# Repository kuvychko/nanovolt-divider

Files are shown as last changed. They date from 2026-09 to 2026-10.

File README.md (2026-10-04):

# nanovolt-divider

A programmable precision attenuator for nanovolt-to-microvolt experiments: it divides an ordinary
bench power supply down by **passive resistive division**, read by an external precision DMM. Three
ratios (1e-5, 1e-6, 1e-7), relay-controlled polarity reversal for ABBA modulation, and a
source-disconnected baseline that opens the source without touching the measurement path.
Calibration is in progress (see [Status](#status)).

| | |
|---|---|
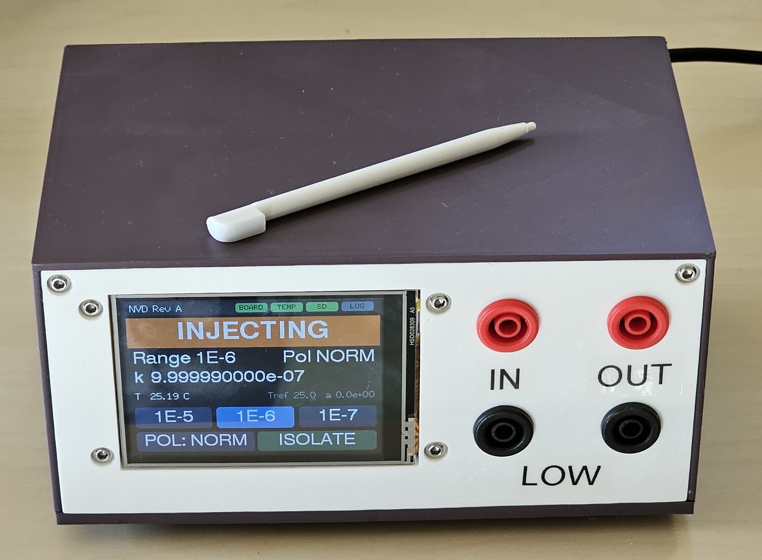
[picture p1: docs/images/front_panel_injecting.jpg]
Front panel, INJECTING on the 1E-6 range
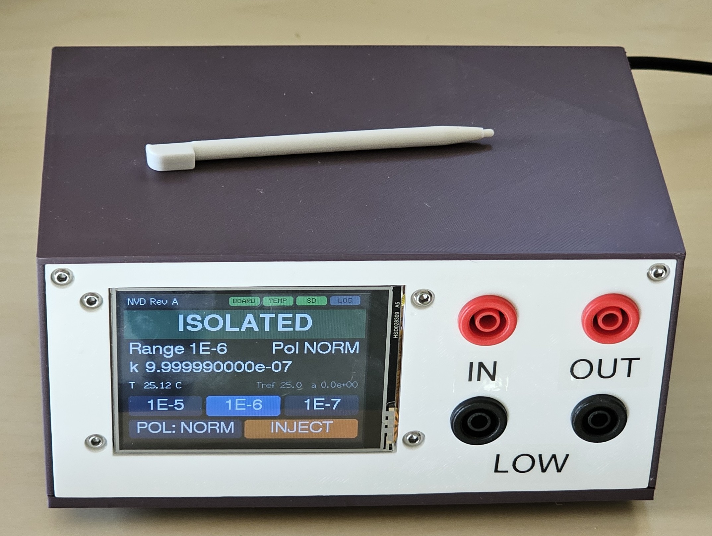
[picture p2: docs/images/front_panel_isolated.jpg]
Front panel, ISOLATED
|  |  |
| INJECTING: K5 set, the source drives the 1E-6 divider | ISOLATED: the source is open at both ends, the 1 Ω and OUT jacks stay connected |

| | |
|---|---|
| Ranges | `1E-5`, `1E-6`, `1E-7`: high legs of 100 kΩ (0.1 %, 5 ppm/°C), 1 MΩ (0.1 %, 10 ppm/°C) and 10 MΩ (1 %) over one shared 1 Ω low leg |
| Polarity | K4 reverses the source *upstream* of the high leg, so relay-contact EMFs reach the output divided by ~1/k |
| Baseline | ISOLATE opens the source at both ends; the 1 Ω, its Kelvin taps and the DMM path are never switched |
| Switching | Five latching relays, pulsed for 20 ms and never held: no continuous coil power |
| Temperature | TMP275 on a slotted island next to the 1 Ω |
| Calibration | Per-range k(T) = k0 [1 + α(T−T0) + β(T−T0)²] with uncertainties, stored in NVS and backed up to microSD |
| Control | SCPI over USB serial, and a 2.8" touchscreen (ESP32 "Cheap Yellow Display") |

## Status

Rev A is built and verified: all relay transitions work, and with 10 V applied all three ratios read
within 0.25 % of nominal, with the ISOLATE reading unchanged by the source. Firmware is 0.2.0.

**Calibration is in progress.** Until it completes, the instrument carries nominal ratios with
tolerance-sized uncertainties. The method, and each result as it comes in, are in
[docs/calibration.md](docs/calibration.md).

## Documentation

| Document | Contents |
|---|---|
| [docs/nanovolt_divider_rev_a.md](docs/nanovolt_divider_rev_a.md) | Design: architecture, relay rules, control, calibration model, BOM |
| [docs/hardware.md](docs/hardware.md) | Circuit, relay states, display harness wiring, board layout and routing rules |
| [docs/development.md](docs/development.md) | Opening the KiCad project, the ERC/DRC baseline, the generators and router, fabrication files |
| [docs/host_interface.md](docs/host_interface.md) | Driving it from a computer: the USB link, the reset-on-open trap, the SCPI contract |
| [docs/calibration.md](docs/calibration.md) | How the ratios are calibrated, the uncertainty budget, and the results so far |
| [firmware/README.md](firmware/README.md) | Building and flashing, the full SCPI command reference, first power-on |

## Repository layout

```
docs/                      design, hardware, development, host interface, calibration
calibration/               calibration result data (summaries and figures)
enclosure/                 SOLIDWORKS parts (.SLDPRT), STEP, and 3D-print files (.3MF, .3DXML)
firmware/                  ESP32 firmware, PlatformIO: relay state machine, SCPI over USB, touch UI,
                           microSD calibration backup and run log
hardware/                  KiCad 10 project
  nanovolt-divider.kicad_pro
  nanovolt-divider.kicad_sch   root sheet: metrology topology (input, relays, high legs, 1 ohm, output)
  control.kicad_sch            ESP32 display-module harness, MCP23017, TMP275, power
  relay_channel.kicad_sch      generic latching-relay channel, instantiated 5x (K1..K5)
  nanovolt-divider.kicad_pcb   board: 60 x 69.1 mm, 2 layers
  nanovolt-divider.kicad_dru   custom DRC rules (1 ohm bridge track width)
  lib/                         project symbol and footprint libraries
  fab/                         Rev A Gerbers and drill files
tools/gen_schematics.py    generates the schematics and the project libraries
tools/gen_pcb.py           generates the placed, unrouted board
tools/route_pcb.py         grid maze router around the hand routes (see docs/hardware.md)
tools/route_hand.py        the hand routes and routing policy: the design intent of the routing
tools/pcb_io.py            pcbnew side of the router: dump pads, apply routes
tools/scpi.py              SCPI terminal for the instrument over USB serial (uv run tools/scpi.py)
```

## Building one

1. **Boards.** Zip the contents of `hardware/fab/` and order (they went to OSH Park). Everything is
   hand-solderable; the BOM is in [§11 of the design doc](docs/nanovolt_divider_rev_a.md#11-bom).
2. **Harness.** Wire the display module to `J7` / `J8` **by signal name, never by pad number**: the
   board silk does not match the module. The table is in
   [docs/hardware.md, Display harness](docs/hardware.md#display-harness).
3. **Enclosure.** Print and assemble it as below.
4. **Firmware.** Build, flash and power on following [firmware/README.md](firmware/README.md).

## Enclosure

The enclosure is 3D-printed. `enclosure/` has the SOLIDWORKS source (`.SLDPRT`), a neutral `.STEP`
and a print-ready `.3MF` for each part: front panel (it also serves as the display bezel), back
panel, base plate (v1), cover (v1), PCB holder, and a wrench for the banana-jack nuts. The version
is in each file name.

Every part prints in PLA on a Prusa i3 MK3S with a 0.4 mm nozzle, using PrusaSlicer's
**0.20 mm QUALITY** preset, 15 % infill, and **no supports**.

Before assembling, heat-set the knurled brass inserts: the M2 ones go into the PCB holder, the M3
ones into the enclosure parts. Fasteners, banana jacks, the display module, and the cables are
listed in [BOM §11.4 and §11.5](docs/nanovolt_divider_rev_a.md#114-front-panel--mechanical).

| | |
|---|---|
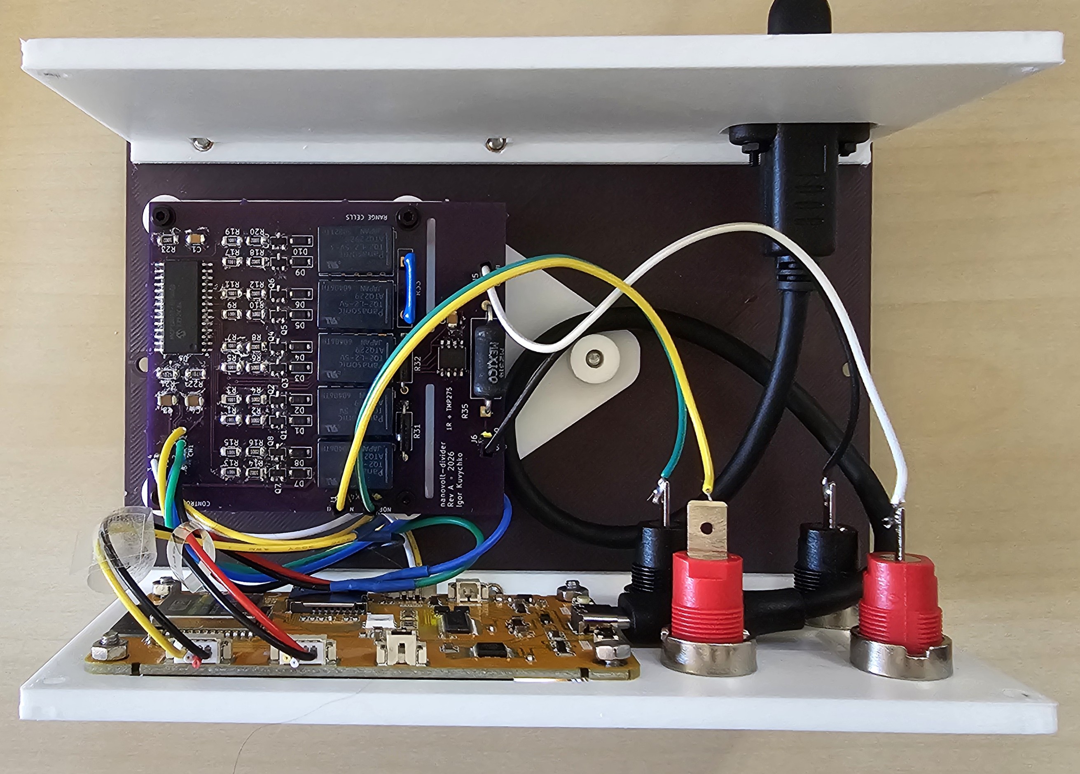
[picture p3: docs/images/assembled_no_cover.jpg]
Assembled, cover off
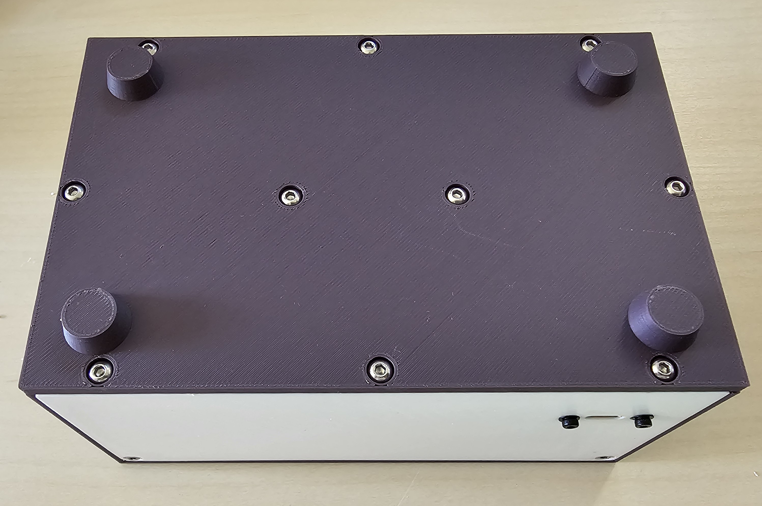
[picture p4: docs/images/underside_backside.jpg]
Base plate and back panel
|  |  |
| Cover off: the board on its holder, the display behind the front panel, and the jacks wired to their pads | Base plate with printed feet, and the back panel with the USB opening |

## Known limitations

* The board's harness silk and F.Fab text describe a different module pinout from the module the
  instrument uses. Wire by signal name (see
  [Display harness](docs/hardware.md#display-harness)).
* The harness cable has no strain relief at the board end; nothing on the board takes that load.

## Datasheets

Not redistributed here. Panasonic TQ relays: catalog ASCTB14E (`industry.panasonic.com`); Ohmite
MOX-700 and Slim-Mox; Vishay Dale RS/NS; Microchip MCP23017; TI TMP275.

## License

* Hardware (`hardware/`), enclosure (`enclosure/`) and documentation (`docs/`, `calibration/`):
  [CERN-OHL-P-2.0](LICENSE-CERN-OHL-P-2.0).
* Firmware (`firmware/`) and tools (`tools/`): [MIT](LICENSE-MIT).

Source location: <https://github.com/kuvychko/nanovolt-divider>. See [LICENSE](LICENSE).

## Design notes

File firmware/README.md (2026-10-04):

# Rev A firmware

Firmware for the ESP32 "Cheap Yellow Display" (ESP32-2432S028R family) that runs the nanovolt divider:

* the relay state machine for K1..K5, through the MCP23017;
* the TMP275;
* per-range calibration k(T) in NVS, with a backup, an append-only history and a CSV run log on the microSD card;
* SCPI over USB serial;
* the touchscreen front panel.

The instrument is controlled over USB from a host computer (e.g. a Raspberry Pi): see
[docs/host_interface.md](../docs/host_interface.md) for the host side, and
[docs/calibration.md](../docs/calibration.md) for how the calibration is measured. **The radio is never
initialised:** there is no Wi-Fi or Bluetooth, and no 2.4 GHz transmitter a few centimetres from a nanovolt path.
The module's RGB LED is held off; it is inside the enclosure.

## Build and flash

The project uses PlatformIO. Install it with `uv tool install platformio`. Set `upload_port` and `monitor_port`
in `platformio.ini` to your module's serial port (they are `COM8` there), and pass `-p <port>` to `tools/scpi.py`.

```
pio run -d firmware -e cyd -e cyd_st7789 -e cyd_sim   # build every environment (plain `pio run` builds only cyd)
pio run -d firmware -e cyd -t upload       # flash
uv run tools/scpi.py -p <port>             # interactive SCPI terminal
uv run tools/scpi.py -p <port> "*IDN?" "SYST:MODE?"  # one-shot
```

| Environment | Use |
|---|---|
| `cyd` | Standard CYD with an ILI9341 panel. The default. |
| `cyd_st7789` | CYD2USB variant (two USB ports) with an ST7789 panel. Use it if `cyd` shows garbage or wrong colours. `DIAG:DISP:INV ON` flips the colour inversion at run time, to help tell the variants apart. |
| `cyd_sim` | No board needed. The MCP23017 and TMP275 are simulated, and every coil pulse is printed as `# PULSE K5 RESET (GPA0) 20 ms`. Use it to check relay sequencing. |

The platform is pinned to `espressif32@7.1.3` (Arduino core 2.0.17) and `LovyanGFX@1.2.30`. Core logging is compiled
out (`CORE_DEBUG_LEVEL=0`), because it would land in the SCPI response stream. The firmware's own unsolicited lines
(the boot banner and the pulse trace) all start with `# `, so a host can skip them.

## How it drives the board

* **I2C is SDA = IO27, SCL = IO18.** See [docs/hardware.md, "Display harness"](../docs/hardware.md#display-harness).
* **Coil table.** The table is in `src/coils.cpp`, and nowhere else. It follows the layout order: GPB0..7 = K4 S, K4 R,
  K1 S, K1 R, K2 S, K2 R, K3 S, K3 R; GPA0 = K5 R, GPA1 = K5 S. GPA2..7 stay inputs.
* **One coil at a time.** Every pulse first confirms that both output latches read back 0. It then sets one bit,
  holds it for the pulse width (20 ms by default), clears it, reads the latches back again, and waits the gap
  (20 ms).
* **The MCP23017 survives an ESP32 reboot.** R23 ties `~RESET` high, so a reboot mid-pulse would leave a coil
  energised. Boot therefore clears OLATA/OLATB before anything else, including before it makes any pin an output.
* **Relay rules ([design §6.3](../docs/nanovolt_divider_rev_a.md#63-relay-safetystate-rules)).**
  * At boot, and on `*RST`, the firmware pulses the safe state: K5 RESET (ISOLATE) first, then K1..K3 RESET, then K4
    RESET.
  * A range or polarity change runs this sequence:
    1. isolate;
    2. RESET the old range (break);
    3. SET the new one (make);
    4. restore INJECT if it was on.

    For example, `RANG 1E-6` while injecting on 1E-5 pulses K5R, K1R, K2S, K5S.
  * INJECT is refused while no range is selected.
* **State is assumed, not measured.** Latching relays cannot be read back. The state shown is what the last successful
  pulses produced. It is `UNKNOWN` until the boot safe state has run, and after any failed pulse or raw `DIAG:PULS`.
  While the state is unknown, all relay commands except `*RST` are refused. On the touchscreen, tap the red banner.
* **No board.** With no MCP23017 answering, the screen shows `NO BOARD` and relay commands return `-241`. The firmware
  re-probes every 2 s. A board that appears later is never pulsed automatically: its state is `UNKNOWN` until
  `*RST`.

### microSD and the shared IO18

The card's SCK is IO18, which is also I2C SCL. The bus stays in I2C mode, and each card access switches it to SPI,
mounts the card, does the work, unmounts and switches back (`bus::SdSession`). This is safe both ways:

* I2C traffic clocks SCK while the card's CS is held high, so the card ignores it.
* SPI clocking toggles SCL while SDA idles high, which never forms an I2C START.

Card access happens only between operations, never during a coil pulse. The touch controller is bit-banged on its own
pins, because the only free SPI host belongs to the card.

Files on the card:

| Path | Contents |
|---|---|
| `/nvd/cal.txt` | Calibration backup (`CAL:EXP` / `CAL:IMP`): one `key=value` line per range, `range= k0= t0= alpha= beta= u_k0_ppm= u_alpha_ppm= tmin= tmax= date="" source=""`. An import requires every field. |
| `/nvd/cal_history.txt` | Every `CAL:SAVE`, appended: a `# CAL:SAVE utc=… boot=…` line and the three records. The firmware never rewrites or deletes it. |
| `/nvd/log_NNNN.csv` | Run log: `ms,utc,event,range,polarity,output,temp_C,factor,note`. It gets a row for every relay change, for every `SYST:LOG:MARK`, and a `TEMP` row every `SYST:LOG:INT` seconds (default 10; 0 turns it off). `utc` is `-` until the host sends `SYST:TIME`. |

`MMEM:CAT?` and `MMEM:DATA?` read these over USB, so the card never has to come out:
`uv run tools/scpi.py --fetch /nvd/cal_history.txt hist.txt`. From Git Bash, prefix the command with
`MSYS_NO_PATHCONV=1`, or Bash rewrites `/nvd/...` into a Windows path.

### Calibration model

```
k(T) = k0 · [1 + alpha (T − T0) + beta (T − T0)²]
u(T) = sqrt(u_k0² + (u_alpha · (T − T0))²)   ppm
```

T is the TMP275 reading. Each range carries its own record, including the span [tmin, tmax] it was measured over.
Before calibration the records are nominal: k0 = 1/(R_H + 1), no tempco, and u_k0 from the part tolerances
(10050 / 10050 / 14142 ppm). Records are stored as one NVS blob per range, so a save is all-or-nothing per range.

## SCPI reference

These rules apply to every command:

* Headers match in long or short form, case-insensitively.
* A leading `:` is optional.
* `;` separates commands on one line. The responses to all the queries on a line come back joined by `;`.
* Errors go to the queue, which `SYST:ERR?` reads. A value that does not exist, such as the factor with no range
  selected or a missing temperature, reads `9.91E+37`.

| Command | |
|---|---|
| `*IDN?` `*RST` `*CLS` `*OPC?` | `*RST` pulses the safe state. |
| `SYST:ERR?` `SYST:VERS?` | |
| `SYST:MODE?` | Full state: `BOARD=,STATE=,RANGE=,POL=,OUTP=,TEMP=,FACTOR=,CAL=,LOG=,BOOT=`. |
| `SYST:TIME <unix s>` / `SYST:TIME?` | UTC from the host, kept in RAM (0 until set). Stamps the run log and the cal history. |
| `SYST:BOOT:COUNT?` `SYST:UPT?` | Boots since the NVS was first written, and seconds since this boot. The count changing mid-run means the instrument restarted. |
| `OUTP ON\|OFF` / `OUTP?` | INJECT / ISOLATE. `OUTP OFF` always pulses, even if already isolated. |
| `POL NORM\|INV` / `POL?` | Changes happen while isolated. |
| `RANG 1E-5\|1E-6\|1E-7\|NONE` / `RANG?` | Break-before-make, while isolated. |
| `SOUR:FACT? [T]` | Calibrated factor of the active range, at the live TMP275 temperature or at T. |
| `CAL:FACT? range[,T]` | `k,u_ppm,in_span` for any range, at the live temperature or at T. `in_span` is 0 outside the record's [tmin, tmax] or with no temperature. |
| `CAL:REC range,k0,T0,alpha,beta,u_k0_ppm,u_alpha_ppm,tmin,tmax,"date","source"` / `CAL:REC? range` | One range's whole record, written atomically: any invalid field rejects the lot. The query returns the same fields after the range. This is the command the calibration write-back uses. |
| `TEMP?` | TMP275, °C. |
| `CAL:RAT [range,]k` / `CAL:RAT? [range]` | k0. The range defaults to the active one. Values more than 10 % from nominal are rejected. |
| `CAL:TC [range,]alpha` / `CAL:TC?` | Ratio tempco, 1/°C. The default 0 means no correction. |
| `CAL:TREF [range,]T0` / `CAL:TREF?` | Reference temperature, °C. |
| `CAL:DATE [range,]"text"` / `CAL:DATE?` | Free text, e.g. an ISO 8601 date. |
| `CAL:NOM? [range]` | Nominal factor, 1/(R_H + 1). |
| `CAL:SAVE` | Writes the working calibration to NVS and appends it to `/nvd/cal_history.txt`. The other `CAL:` edits change only the working copy (`SYST:MODE?` shows `CAL=UNSAVED`). If the history append fails, the save still stands and `-250` is queued. |
| `CAL:DEF` | Resets the working copy to nominal. |
| `CAL:EXP` / `CAL:IMP` | Writes the working copy to `/nvd/cal.txt`, or reads it back from there. `CAL:SAVE` after an import. |
| `SYST:LOG ON\|OFF` / `SYST:LOG?` | Starts a new `/nvd/log_NNNN.csv`, or stops logging. |
| `SYST:LOG:FILE?` `SYST:LOG:MARK "text"` `SYST:LOG:INT s` | Log file name, a note row (e.g. `"A forward"` during an ABBA run), and the temperature-row interval. |
| `SYST:BOOT:SAFE ON\|OFF` | Whether boot pulses the safe state. Stored in NVS; the default is ON. |
| `MMEM:CAT? ["dir"]` | `"name",size,...` for a directory, `/nvd` by default. |
| `MMEM:DATA? "path"[,offset[,length]]` | Up to 65536 bytes of a file, as an IEEE 488.2 definite-length block `#<n><len><bytes>` followed by `\n`. Must be the only command on its line. |
| `DIAG:I2C?` | Bus scan. Expect `0x20,0x48` with the board connected. |
| `DIAG:MCP?` | MCP23017 register dump. |
| `DIAG:PULS K1..K5,SET\|RES` | One raw pulse, bypassing the rules. Leaves the state `UNKNOWN`. |
| `DIAG:PULS:WIDT ms` / `DIAG:PULS:GAP ms` | 5..100 ms. Stored in NVS. |
| `DIAG:TRAC ON\|OFF` | Prints each pulse as `# PULSE ...`. |
| `DIAG:PINS?` | IO18/IO27 read with internal pull-downs: `PULLUP` means an external pull-up is fitted. |
| `DIAG:SD?` | Card type and size. |
| `DIAG:TOUC:CAL` / `DIAG:TOUC?` | Runs the 3-point touch calibration, or returns the current raw and mapped touch point. Holding the screen at power-up also starts the calibration. |
| `DIAG:DISP:INV ON\|OFF` | Panel colour inversion (not stored). |

## First power-on with the board

Before you start, flash the `cyd` build with the module alone, and set `SYST:BOOT:SAFE OFF`. That way the first coil
pulses are ones you fire by hand, not five at once at boot.

1. **Harness.** Land every wire by signal name ([docs/hardware.md, "Display harness"](../docs/hardware.md#display-harness)). The J7 silk numbers are
   reversed against the module. With the power off, buzz the harness from the module pins to the pads:

   | Module pin | Board pad |
   |---|---|
   | 5V | `J7` pad 3 |
   | GND (UART/power connector) | `J7` pad 4 |
   | GND (3V3 connector) | `J8` pad 1 |
   | IO18 | `J8` pad 2 |
   | IO27 | `J8` pad 3 |
   | 3.3V | `J8` pad 4 |

   A reversed 5 V would reach the coil drivers the moment USB is plugged in, so this check comes before any power.
2. **Power on.** The banner should read `STATE UNKNOWN`, and the `BOARD` and `TEMP` status lights should be green.
3. `DIAG:I2C?` should return `0x20,0x48`. `DIAG:PINS?` should now report `PULLUP` on both pins: those are R21/R22,
   because the module itself has none (with the module alone, `DIAG:PINS?` reads `IO18=NONE,IO27=NONE`).
4. `DIAG:MCP?` should show `IODIRA=0xFC`, `IODIRB=0x00` and both `OLAT` registers `0x00`.
5. `TEMP?` should give a plausible room temperature.
6. `DIAG:TRAC ON`, then pulse each coil by hand, listening for the click and ideally watching the collector on a scope:

   ```
   DIAG:PULS K5,RES
   DIAG:PULS K5,SET
   DIAG:PULS K5,RES
   ```

   Repeat for K1..K4. With a meter on the contacts, check each relay's pole against the state table in the top-level
   README.
7. `*RST` should pulse the whole safe state. Then `SYST:BOOT:SAFE ON`, and power-cycle to confirm the boot sequence.
8. Walk the ranges with `OUTP ON`, `RANG 1E-6`, `POL INV` and so on, meter the output, and check `SYST:ERR?` is clean.

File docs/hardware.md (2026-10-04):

# Hardware

The Rev A circuit, the display harness, the board layout and the routing rules. Building and flashing are in
[firmware/README.md](../firmware/README.md); regenerating and checking the design files is in
[development.md](development.md); the design rationale and BOM are in
[nanovolt_divider_rev_a.md](nanovolt_divider_rev_a.md).

## Circuit

### Hierarchy

```
nanovolt-divider.kicad_sch (root)
+-- CONTROL          control.kicad_sch
+-- RANGE_1E5 (K1)   relay_channel.kicad_sch
+-- RANGE_1E6 (K2)   relay_channel.kicad_sch
+-- RANGE_1E7 (K3)   relay_channel.kicad_sch
+-- POLARITY  (K4)   relay_channel.kicad_sch
+-- INJECT    (K5)   relay_channel.kicad_sch
```

`relay_channel.kicad_sch` exposes `SET`, `RESET`, `A_COM`, `A_NC`, `A_NO`, `B_COM`, `B_NC`, `B_NO`.
Each instance contains one Panasonic TQ2-L2-5V (2-coil latching DPDT) and two MMBT2222A low-side
coil drivers with 1N4148W flyback diodes.

### Relay states

| Relay | RESET (NC) | SET (NO) |
|---|---|---|
| K4 POLARITY | normal (`SRC_P` = `NORMAL_IN_P`) | inverted |
| K1..K3 RANGE | open at both ends | range active (only one at a time) |
| K5 INJECT | ISOLATE - both legs open (1 ohm and DMM path untouched) | INJECT |

K1..K3 use **both** poles of their relay: pole A breaks the top of the high leg (`R*_IN`), pole B
breaks the bottom (`R*_OUT`). A deselected resistor is therefore isolated at both ends and never
loads `RANGE_BUS`, which matters most on the 10 M range.

K5 does the same for the source as a whole: pole A breaks the high side (`RANGE_BUS` -> `MEAS_NODE`)
and pole B breaks the return (`SRC_RTN` -> `ANALOG_RTN`). In ISOLATE the source is disconnected
from the 1 ohm and the DMM path at both ends, so nothing of it - not its output capacitance, not its
leakage to earth - remains attached to the measurement node.

### Control wiring

* Controller: a 2.8" ESP32 touch-TFT module, a "Cheap Yellow Display" (ESP32-2432S028R family),
  mounted off-board and connected by three of its own pigtails (see [Display harness](#display-harness)).
* The pigtails are **soldered** to pads at the board end; the module end keeps its connector, so
  the display still unplugs. The panel jacks (`J1`, `J2`, `J5`, `J6`) are hard-wired the same way.
* Only the six live conductors have pads: `J7` (5 V, GND) and `J8` (GND, SCL, SDA, 3V3). Both GND
  wires are run: `J7`'s returns the pulsed coil current and `J8`'s serves I2C. They are the same
  net, but two conductors cut the shared IR drop in the cable. Do not collapse them to one wire.
* MCP23017 (I2C 0x20) drives the ten coil lines: GPB0..GPB7 = K4 SET, K4 RESET, K1 SET, K1 RESET,
  K2 SET, K2 RESET, K3 SET, K3 RESET; GPA0 = K5 RESET, GPA1 = K5 SET; GPA2..GPA7 spare. The order
  follows the board: in the driver columns' left-to-right order the lines fan out without a
  crossing or a via. The firmware maps GPIO to coil by table.
* TMP275 (I2C 0x48, `A2:A0` all on `DGND`) sits next to the 1 ohm resistor, thermal proximity only.
  It tracks the *change* in the 1 ohm region's temperature for the ratio correction, which needs
  short-term repeatability (12-bit, 0.0625 C) rather than absolute accuracy (+/-0.5 C). SOIC-8, so the
  whole board can be hand-soldered.
* The control ground is the global net `DGND`, deliberately not `GND`, so it cannot be merged with
  the floating analog return (`SRC_RTN` / `ANALOG_RTN`) by accident.

### Display harness

The module has three 4-pin connectors:

| Module connector | Signals, in the order printed on the module |
|---|---|
| UART / power | RXD, TXD, GND, 5V |
| 3V3 | 3.3V, IO35, *(nc)*, GND |
| SPI | IO23 (MOSI), IO19 (MISO), IO18 (SCK), IO27 (CS) |

Wire them to the board like this:

| Board pad | Net | Wire from module | Pad silk |
|---|---|---|---|
| `J7` pad 3 | `+5V` | UART / power: **5V** | `P1` `3` |
| `J7` pad 4 | `DGND` | UART / power: **GND** | `P1` `4` |
| `J8` pad 1 | `DGND` | 3V3: **GND** | `CN1` `1` |
| `J8` pad 2 | `SCL` | SPI: **IO18** | `CN1` `2` |
| `J8` pad 3 | `SDA` | SPI: **IO27** | `CN1` `3` |
| `J8` pad 4 | `+3V3` | 3V3: **3.3V** | `CN1` `4` |
| - | - | cut back and insulate: RXD, TXD, IO35, the nc pin, IO23, IO19 | - |

* **Land every wire by signal name, never by pad number.** The silk numbers on the board do not
  match this module: on `J7`, module pin 3 is GND but pad `3` is `+5V`, so matching numbers would
  feed the coil drivers a reversed 5 V supply. The `J8` pad row is fed by two different pigtails, so
  its "CN1 1-4" silk refers to no single connector. The F.Fab text on the board (`SCL_IO22`,
  `VIN_5V`) does not match either. The schematic symbols carry the correct module labels.
* **Why IO18 / IO27.** I2C needs two pins that can drive open-drain. IO35 cannot (ESP32 GPIO34-39
  are input-only), and RXD / TXD carry the USB-serial SCPI interface, which leaves the SPI
  connector. Firmware: `Wire.begin(/*SDA*/ 27, /*SCL*/ 18)`.
* **IO18 is shared with the microSD slot** (its SCK; the slot has its own CS on IO5). With the card's
  CS deasserted, I2C traffic on IO18 does not disturb it; the firmware switches IO18 between I2C and
  SPI around each card access (see [firmware/README.md](../firmware/README.md)). The module has no pull-ups on IO18 or IO27,
  so `R21` / `R22` set the bus pull-up.
* Both GND conductors run from different connectors: the UART / power GND to `J7` (coil current) and
  the 3V3 connector's GND to `J8` (I2C).

## Board

| | |
|---|---|
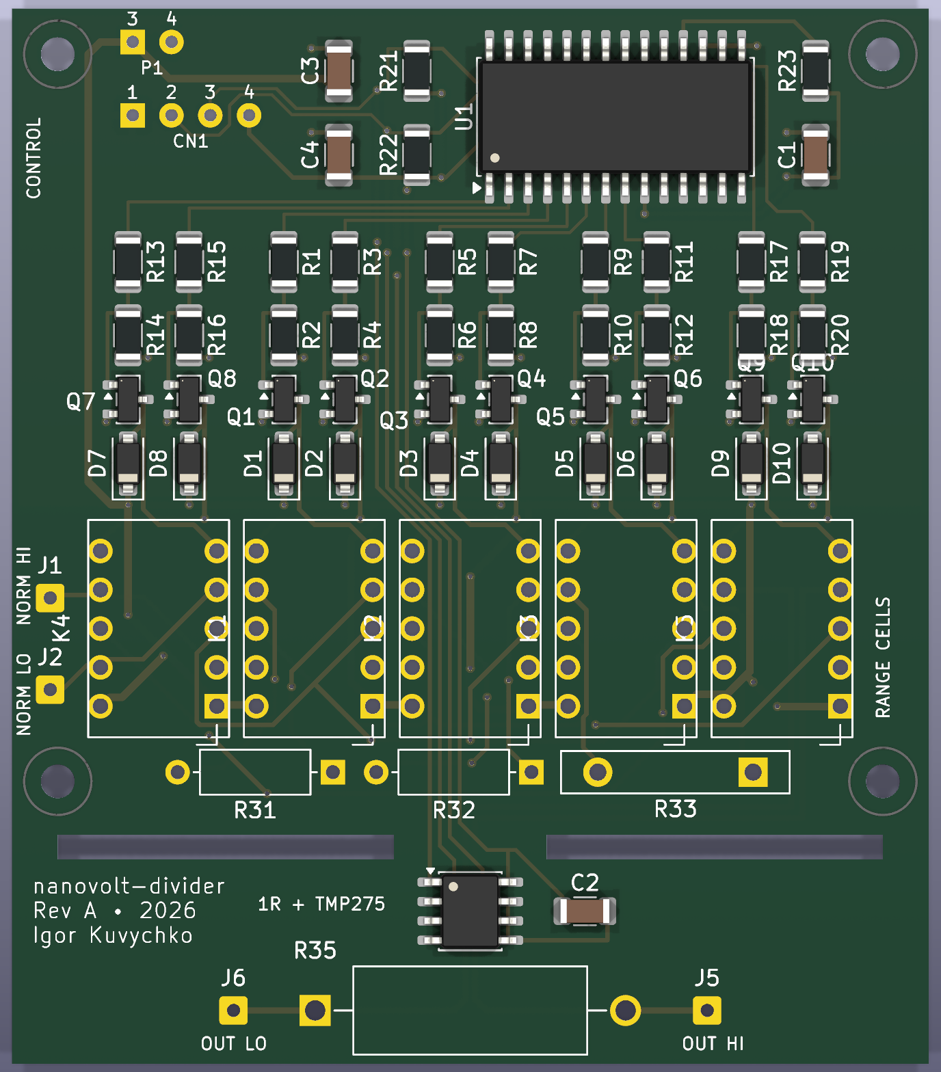
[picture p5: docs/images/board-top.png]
Rev A board, top (render)
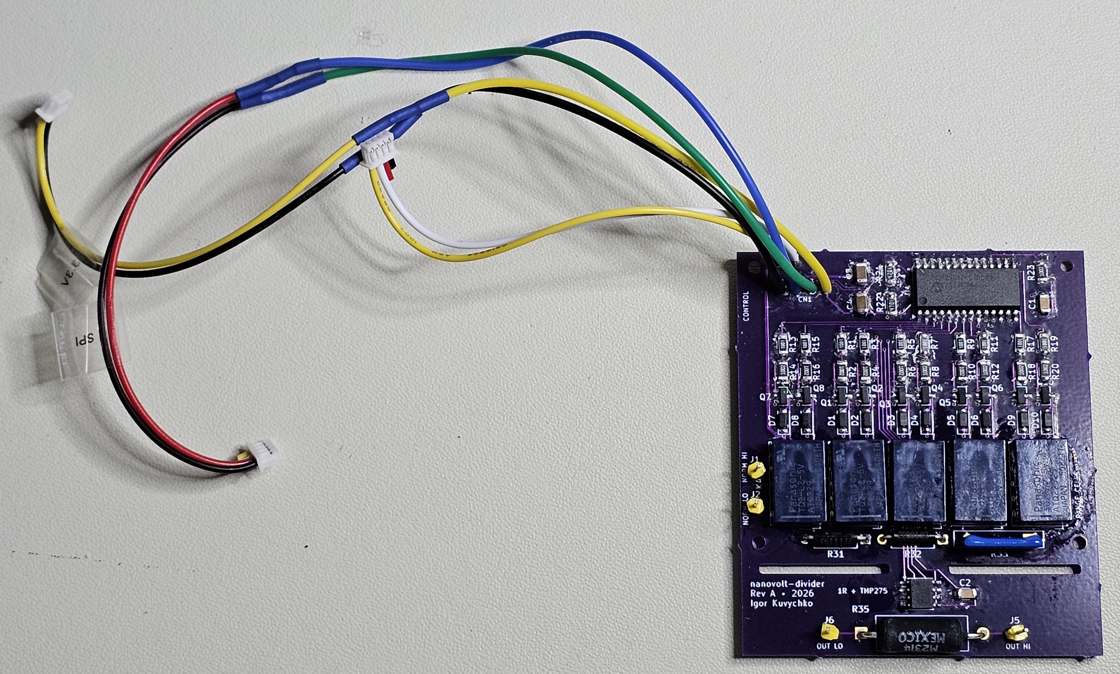
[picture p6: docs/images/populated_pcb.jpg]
Rev A board, populated, with the display harness
|  |  |
| Layout render | Populated Rev A with the harness pigtails soldered to `J7` / `J8` |

* 60 x 69.1 mm, two layers, laid out top-down: one control band, ten coil-driver columns, the five
  relays, then the three high legs flat in one row.
* **The control band is a single row**: `[H1] P1/CN1 | C3,C4 | R21,R22 | U1 | R23,C1 [H2]`. The bulk
  caps sit at the power entry, the I2C pull-ups between the harness and `U1` so the bus runs left to
  right, and `C1` beside `U1`'s power pins.
* **Driver cells.** Each relay carries its SET/RESET driver pair directly above it, so `RANGE_BUS`
  runs as one short chain across the three range cells.
* **The three high legs lie flat in one row** under the relays. `A_NO` and `B_NO` are both on each
  relay's upper contact row, and the flat, offset placement keeps both runs to 2-5 mm.
* **M2 mounting holes.** The smaller courtyard lets the holes sit closer to `K4`/`K5` above and the
  slots below, which saves board height.
* The relay coils are pulsed for 20 ms and never held, so their average dissipation is ~0 and they
  can sit next to the range resistors. The continuously powered parts (MCP23017, harness pads, bulk
  caps) stay at the top edge, away from `MEAS_NODE`.
* **The 1 ohm island.** Two slots leave a 10 mm centre bridge and 3 mm bridges at both board edges
  for stiffness; `MEAS_NODE`, `ANALOG_RTN` and the TMP275 lines cross the centre one. The OUT HI / OUT
  LO wire pads are at the resistor's own terminals. Both lower mounting holes sit *above* the slots:
  a screw on the island would add a thermal and mechanical-stress path to the precision resistor.
* The TMP275 sits on the island above `R35`. What couples the sensor to `R35` is the island copper,
  not the air over the body.
* **`J1` / `J2` sit beside `K4`**, opposite the K4 pole-B contacts they wire to, clear of the lower
  left mounting hole.
* `DGND` pour on B.Cu covers the digital circuitry (control cluster and coil drivers). The only
  copper keepout is over the 1 ohm island.
* Panel parts (four banana jacks) terminate on solder-wire pads. Nothing is wired panel-to-panel,
  so every conductor appears in the netlist.

### Routing

The precision path, the driver cells and the whole control band are hand-laid
(`tools/route_hand.py`); a grid maze router (`tools/route_pcb.py`) filled in the rest around them.
Rules the routing follows, and that hand edits should keep:

* **`MEAS_NODE` and `ANALOG_RTN` run as one tight pair on B.Cu** from K5 to R35: 0.4 mm, 0.3 mm
  apart, via-free. `ANALOG_RTN` is on the side facing the high-leg pads, so it rather than
  `MEAS_NODE` takes any surface leakage from `R*_IN`. The pair crosses the centre bridge on the
  board's centre line and only splits under R35, along its axis, so the current loop is the
  resistor itself and both terminals have the same copper path back to the board.
* **Kelvin at R35.** The injection current lands on R35's pads from the inside; J5 / J6 (the DMM)
  leave them on the outside on F.Cu, and carry no current.
* **Source-side and low-side copper keep 0.5 mm apart on the same layer.** `SRC_P`, `NORMAL_IN_*`
  and `R*_IN` sit at the source voltage; `RANGE_BUS`, `R*_OUT` and `MEAS_NODE` at the bottom of the
  selected high leg. Leakage between them is a resistor across the high leg - 10 ppm at 1e12 ohm on
  the 10 M range. Where the two chains must cross they do it on opposite layers, through 1.6 mm of
  FR4 bulk. `SRC_RTN` / `ANALOG_RTN` are in neither class: leakage into them only loads the source.
* **Nothing reaches the 1 ohm island except over the centre bridge**, and the bridge carries no
  vias. A track over an edge bridge would bring heat in at one end of R35, and a temperature
  difference between its terminals is a thermal EMF in series with the measurement.
* **The TMP275 lines are one F.Cu spine**: SDA, SCL, DGND, +3V3 at 0.65 mm pitch, down the gap
  between the K1 and K2 driver pairs, through the left half of K2, under R32's body and onto the
  island left of the pair. The precision chains cross it on B.Cu.
* **Driver cells are identical.** Each column is the same template: the base node runs straight
  from the 1k to the 10k, which is why R1-R20 sit at 270 degrees. DGND goes to the B.Cu pour through
  a via beside the 10k and one beside the emitter; cathodes drop to a +5V bus on B.Cu at y 32.5 along
  the bottom of the pour.
* **One coil crossing per relay, the same for all five.** The SET column feeds the right-hand coil
  pin and the RESET column the left: SET stays on F.Cu, RESET drops to B.Cu. That leaves the left
  half of each relay's top free on F.Cu, which is how the TMP275 spine gets into K2.
* **The MCP23017 fan-out has no crossings and no vias.** Eight lines drop off U1's lower row in the
  driver columns' order, five of them left in 0.2 mm lanes at 0.4 mm pitch, and K5's two leave under
  the package to the right. SDA, SCL and 3V3 reach U1 under its body, stacked in the order they drop
  to pins 13, 12 and 9.
* **The control band's vias are each unavoidable:** the TMP275 spine's SDA, SCL and 3V3 each rise on
  B.Cu past the coil lanes; R21's 3V3 pad is fenced in by SDA and SCL; and C1/R23 sit beyond the K5
  lines, so their 3V3 hops from pin 9 on B.Cu. SDA and SCL squeeze between C3 and C4 in two 0.2 mm
  lanes; +5V comes down the left edge from P1.

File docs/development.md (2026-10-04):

# Development

Working on the KiCad design: opening it, the ERC/DRC baseline, the generators and router, and the
fabrication files. Commands run from the repository root. The circuit and board themselves are described in
[hardware.md](hardware.md).

## Working with the design files

Open `hardware/nanovolt-divider.kicad_pro` in KiCad 10. The project library
`hardware/lib/nanovolt-divider.kicad_sym` holds the TQ2-L2-5V relay, the TMP275, the `DGND` power
symbol and the two ESP32 harness pigtail landings. These carry the module's own pin names
(`SCL_IO18`, `SDA_IO27`, ...) rather than `Pin_1..Pin_4`, so a wire on the wrong pin is visible in
the schematic. The harness footprints are kept exactly as fabricated (`HARNESS_PADS_REV_A` in
`gen_schematics.py`), which is why their F.Fab names differ; see
[Display harness](hardware.md#display-harness). Footprints for the
relay, the precision resistors and the harness pads are in `hardware/lib/nanovolt-divider.pretty`;
the TMP275 uses the stock `Package_SO:SOIC-8_3.9x4.9mm_P1.27mm`. Everything else is stock KiCad.

ERC, DRC and exports from the command line:

```
kicad-cli sch erc --severity-all --exit-code-violations hardware/nanovolt-divider.kicad_sch
kicad-cli sch export pdf --output build/schematic.pdf hardware/nanovolt-divider.kicad_sch
kicad-cli pcb drc --severity-error --severity-warning hardware/nanovolt-divider.kicad_pcb
```

The baseline is ERC clean, and DRC 0 errors, 0 unconnected and 56 `silk_over_copper` warnings
(silkscreen clipped by solder mask at pad openings, which the fab does anyway). With
`--schematic-parity` there are also 2 `footprint_symbol_field_mismatch` warnings: the Description
field of `J7` and `J8` names the display module, while the board keeps the fabricated text. They
are metadata only. Check that a change does not add to this baseline.

### Generators

`tools/gen_schematics.py` generates all schematic files, the project symbol library and the project
footprints; re-run it after editing the script. It will **not** overwrite an existing
`nanovolt-divider.kicad_pro`, which KiCad owns and which holds the DRC severities. It writes its
files directly with derived UUIDs, so re-running it leaves the working tree clean.

`tools/gen_pcb.py` writes a placed, **unrouted** board from scratch, so running it discards the
routing and any hand edits. The router then reproduces the committed routing exactly (it deletes
every track before applying its own):

```
"C:/Program Files/KiCad/10.0/bin/python.exe" tools/pcb_io.py dump  hardware/nanovolt-divider.kicad_pcb %TEMP%/nvd_geom.json
uv run tools/route_pcb.py %TEMP%/nvd_geom.json %TEMP%/nvd_routes.json
"C:/Program Files/KiCad/10.0/bin/python.exe" tools/pcb_io.py apply hardware/nanovolt-divider.kicad_pcb %TEMP%/nvd_routes.json
```

**A regenerated board produces a large, meaningless diff.** `kicad-cli pcb upgrade` assigns fresh
random UUIDs to the graphics it materialises inside stock footprints, so about 683 of the board's
~1400 UUIDs change on every run, and `kicad-cli` writes CRLF while `.gitattributes` pins the repo to
LF. Neither is a real change. Before acting on a board diff, normalise both sides and compare:

```python
import re, io, subprocess
strip = lambda t: re.sub(r'"[0-9a-f]{8}-[0-9a-f]{4}-[0-9a-f]{4}-[0-9a-f]{4}-[0-9a-f]{12}"', '"U"',
                         t.replace("\r\n", "\n"))
cur  = io.open("hardware/nanovolt-divider.kicad_pcb", "rb").read().decode("utf-8")
head = subprocess.run(["git", "show", "HEAD:hardware/nanovolt-divider.kicad_pcb"],
                      capture_output=True).stdout.decode("utf-8")
print(strip(head) == strip(cur))    # True -> nothing changed; restore the file, do not commit it
```

Read both sides as bytes and decode UTF-8 explicitly. Decoding one side through
`subprocess.run(text=True)` uses the locale codec and manufactures fake differences around non-ASCII
characters - KiCad's stock `SolderWire` footprint description genuinely contains a U+FFFD.

What proves a board change is real is the exported netlist and an ERC/DRC comparison, not the
file diff.

## Fabrication files

`hardware/fab/` holds the Rev A Gerbers and drill files exactly as sent to the fab (OSH Park, git
tag `rev-a`). `.gitattributes` marks the folder `-text` so git leaves their CRLF line endings alone.
To order boards, zip the folder's contents. Two things to know about them:

* Their metadata says `Rev0` (`TF.ProjectId` in every Gerber, `Revision` in the job file). The
  copper is the Rev A board's: re-plotting the board and diffing against these files leaves only the
  creation date and the drill marks.
* They are plotted with drill marks **off**. The board file's stored plot settings have them on
  (small), so `kicad-cli pcb export gerbers --board-plot-params` adds a 0.3 / 0.35 mm flash at every
  hole on the copper and mask layers. Turn them off when re-plotting.

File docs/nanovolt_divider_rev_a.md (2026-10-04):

# Programmable Nanovolt Divider / Precision Attenuator
## Rev A design

**Revision:** Rev A, as built (fab files in `hardware/fab/`, enclosure in `enclosure/`)  
**Primary use:** calibrated low-level DC injection and sub-LSB metrology with an external precision DMM

---

## 1. Purpose

The instrument converts an ordinary, controllable DC source into a stable and calibrated
nanovolt-to-microvolt signal by **passive resistive attenuation**, rather than synthesizing nanovolts
directly.

The method it supports is a LAN- or USB-controlled bench supply, a ~1:10^n divider, a 5½-digit DMM on
its most sensitive range, and ABBA modulation with averaging. With an HP 3478A on its 30 mV range,
that combination recovers signals well below the meter's 100 nV quantization step, down to tens of
nanovolts.

> **A conventional voltage source + passive precision attenuation + reversal + source-disconnected baseline + calibration + averaging.**

The precision signal path is kept as passive and electrically quiet as practical.

---

## 2. Capabilities

1. **Three programmable attenuation ranges**
   - approximately `1e-5`
   - approximately `1e-6`
   - approximately `1e-7`

2. **Shared 1 Ω low-leg resistor**
   - permanent part of the DMM measurement path
   - never switched out of the low-voltage path
   - the "heart" of the divider

3. **Programmable polarity reversal**
   - a latching relay
   - reversal occurs upstream of the precision divider

4. **Programmable injection / isolation**
   - a latching relay upstream of the 1 Ω resistor
   - `INJECT`: the source drives current through the 1 Ω resistor
   - `ISOLATE`: the source is disconnected at both ends while the DMM remains connected across the same 1 Ω resistor
   - a physically meaningful zero that does not perturb the low-voltage measurement path

5. **Temperature monitoring**
   - one TMP275 adjacent to the 1 Ω resistor
   - drives the stored temperature correction of the ratio
   - the correction depends on the *change* in temperature since calibration, so short-term repeatability
     (12-bit, 0.0625 °C) matters and absolute accuracy (±0.5 °C) does not

6. **Stored calibration**
   - per range: calibrated ratio, reference temperature, temperature coefficients, uncertainties, valid temperature span
   - stored in nonvolatile memory, backed up and audit-logged on microSD

7. **Local user interface**
   - integrated 2.8" ESP32 + 320×240 resistive-touch TFT module
   - touchscreen control of range, polarity and injection/isolation
   - the display shows range, polarity, output state, calibrated factor, temperature and status

8. **Remote control**
   - SCPI over USB serial. There is no wireless interface: the radio is never initialised.

---

## 3. Non-goals

The instrument is deliberately not a general-purpose precision source:

- no direct nanovolt generation with DACs/op-amps
- no precision voltage reference
- no closed-loop output regulation
- no internal DMM/ADC as the metrology reference
- no control of the external supply
- no sub-nanovolt absolute-accuracy claims
- no active analog circuitry in the precision signal path

The external supply is the voltage source; the external DMM is the measurement reference.

---

## 4. Electrical architecture

### 4.1 Signal path

Five identical dual-coil latching relay channels:

| Relay | Function |
|---|---|
| K1 | Select 100 kΩ high leg (`~1e-5`) |
| K2 | Select 1 MΩ high leg (`~1e-6`) |
| K3 | Select 10 MΩ high leg (`~1e-7`) |
| K4 | Polarity reversal |
| K5 | Injection enable / isolation |

Only one range relay is active at a time.

Nominal divider factors are

\[
k = \frac{R_L}{R_H + R_L}
\]

with \(R_L = 1\ \Omega\):

| Range | High leg | Nominal factor |
|---|---:|---:|
| `1e-5` | 100 kΩ | 9.999900001e-6 |
| `1e-6` | 1 MΩ | 9.999990000e-7 |
| `1e-7` | 10 MΩ | 9.999999000e-8 |

Actual factors are determined by calibration and stored in the instrument ([calibration.md](calibration.md)).

### 4.2 Zero / isolation

The 1 Ω low-leg resistor is **never shorted and never removed from the DMM path**.

In `INJECT` mode:

```text
selected high leg -> injection node -> 1 Ω -> analog return
                                  |           |
                                DMM HI      DMM LO
```

In `ISOLATE` mode:

```text
selected high leg -> OPEN

                    injection node -> 1 Ω -> analog return
                         |                    |
                       DMM HI               DMM LO
```

The zero therefore keeps the same 1 Ω resistor, PCB traces, solder joints, output connector, cable and
DMM terminals. Only the injected current is removed.

---

## 5. System block diagram

```mermaid
flowchart LR
    subgraph CTRL["Front / Control Section"]
        UI["2.8 in ESP32 Touch TFT"]
        IO["MCP23017\nI²C GPIO expander"]
        T["TMP275\ntemperature sensor"]
        UI <-->|I²C / control| IO
        UI <-->|I²C| T
    end

    subgraph NORMAL["Precision Divider"]
        NIN["NORMAL IN\n+ / -"]
        POL["K4\nPOLARITY"]
        RSEL["K1 / K2 / K3\nRange select"]
        RH["100 kΩ / 1 MΩ / 10 MΩ"]
        INJ["K5\nINJECT / ISOLATE"]
        NIN --> POL --> RSEL --> RH --> INJ
    end

    NODE["Measurement node"]
    RL["1 Ω precision low leg"]
    OUT["DIVIDER OUT\n+ / -"]

    NORMAL --> NODE --> RL --> OUT

    IO -. "10 relay-coil control lines" .-> NORMAL
    T -. "thermal proximity only; no analog connection" .-> RL
```

---

## 6. Control architecture

### 6.1 Controller

An integrated **2.8" ESP32 touch-display module**, a "Cheap Yellow Display" (ESP32-2432S028R
family): ESP32, CH340 USB serial, 320×240 ILI9341 TFT, XPT2046-type resistive touch, microSD slot.

Its three 4-pin connectors are UART / power (RXD, TXD, GND, 5V), 3V3 (3.3V, IO35, nc, GND) and SPI
(IO23 MOSI, IO19 MISO, IO18 SCK, IO27 CS). The board takes 5 V and GND from the first, 3.3 V and GND
from the second, and the I²C bus from the third: **SDA = IO27, SCL = IO18**. The pad-by-pad wiring is
in [hardware.md, "Display harness"](hardware.md#display-harness).

### 6.2 GPIO expansion

Five TQ2-L2 relays need ten coil-control outputs (5 × SET, 5 × RESET), provided by an **MCP23017**
I²C GPIO expander. Each output drives an identical low-side transistor stage:

```text
MCP23017 GPIO
    |
   1 kΩ
    |
MMBT2222A base
    |
10 kΩ pulldown to DGND

relay coil -> MMBT2222A collector
MMBT2222A emitter -> DGND
1N4148W flyback diode across relay coil
```

The same I²C bus carries the TMP275 (address 0x48, `A2`/`A1`/`A0` all on `DGND`).

### 6.3 Relay safety/state rules

1. Power up into a deterministic safe state.
2. Establish `ISOLATE` before configuring other relay states.
3. Only one range relay may be active at a time.
4. Range changes use break-before-make.
5. Polarity changes occur while isolated.
6. Relay coils are pulsed only briefly; they are never continuously energized.

The firmware enforces all six; see `firmware/README.md`.

---

## 7. Mechanical / thermal architecture

The enclosure has two physically distinct regions.

### Control / warm / noisy region

- ESP32 + touchscreen
- MCP23017
- relay-driver electronics
- USB/power wiring

### Precision / quiet region

- relay contacts
- precision high-leg resistors
- 1 Ω resistor
- TMP275
- output connector

The enclosure is 3D-printed plastic, with the front panel doubling as the display bezel.

### 1 Ω thermal region

The 1 Ω resistor gets special layout treatment:

- near the output connector,
- minimal low-level trace length,
- output/sense traces branch directly from the resistor terminals (Kelvin),
- TMP275 alongside,
- no relay coil or TFT/backlight heat nearby,
- PCB slots that leave the resistor on an island joined by narrow bridges, to reduce thermal
  conduction from the rest of the board.

---

## 8. Calibration model

Each range stores a record:

```text
k(T) = k0 [1 + α(T − T0) + β(T − T0)²]
u(T) = sqrt(u_k0² + (u_α (T − T0))²)          (ppm, k = 1)
```

with T the TMP275 reading on the 1 Ω island, valid over the span [Tmin, Tmax] it was measured over,
plus a date and a provenance string. The instrument answers "the ratio at this board temperature"
directly (`CAL:FACT? <range>,<T>` → k, uncertainty, in-span flag). Every saved calibration is
appended to an audit trail on the SD card. Before calibration the records are nominal, with
tolerance-sized uncertainties. How the records are measured is in [calibration.md](calibration.md).

---

## 9. SCPI interface

SCPI over USB serial, 115200 8N1. The core commands:

```text
*IDN?  *RST  *OPC?  SYST:ERR?
OUTP ON|OFF         INJECT / ISOLATE
POL NORM|INV
RANG 1E-5|1E-6|1E-7|NONE
TEMP?
SOUR:FACT?          calibrated factor of the active range
CAL:FACT? <range>[,<T>]
CAL:REC <range>,...  /  CAL:REC? <range>
SYST:MODE?          whole state in one line
```

The full command reference is in `firmware/README.md`; what a host program relies on (error queue,
completion, timing, reset detection) is in [host_interface.md](host_interface.md).

---

## 10. KiCad schematic organization

The schematic is hierarchical:

```text
nanovolt-divider.kicad_sch        # root / system architecture
|
+-- control.kicad_sch
|     ESP32/display interface
|     MCP23017
|     TMP275 interface
|     power/decoupling
|
+-- relay_channel.kicad_sch       # same file instantiated 5 times
      K1 RANGE_1E5
      K2 RANGE_1E6
      K3 RANGE_1E7
      K4 POLARITY
      K5 INJECT
```

The root sheet owns the metrology topology:

- the input
- the 100 kΩ / 1 MΩ / 10 MΩ divider network
- the 1 Ω low leg
- the output terminals

`relay_channel.kicad_sch` is generic and exposes:

```text
SET
RESET

A_COM
A_NO
A_NC

B_COM
B_NO
B_NC
```

Because all five channels share one sheet, KiCad's multichannel / repeat-layout tooling can replicate
the driver layout after one channel is placed and routed.

---

## 11. BOM

### 11.1 Precision / analog components

| Qty | Part | Mfr. part number | Function / notes |
|---:|---|---|---|
| 1 | Vishay/Dale 1 Ω wirewound | `RS02C1R000FE70` | Shared low leg, 1%, 2.5 W, through-hole |
| 1 | Ohmite 100 kΩ metal film | `MOX70031003BZE` | `1e-5` range, 0.1%, 5 ppm/°C |
| 1 | Ohmite 1 MΩ metal film | `MOX70031004BYE` | `1e-6` range, 0.1%, 10 ppm/°C |
| 1 | Ohmite 10 MΩ thick film | `SM102031005FE` | `1e-7` range, 1% |
| 5 | Panasonic latching relay | `TQ2-L2-5V-3` | K1–K5 |
| 1 | TI temperature sensor, SOIC-8 | `TMP275AIDR` | Temperature of the 1 Ω region, I²C 0x48 |

### 11.2 Relay-driver / control components

| Qty | Part | Mfr. part number | Function / notes |
|---:|---|---|---|
| 10 | NPN transistor, SOT-23 | `MMBT2222A` | Two low-side coil drivers per relay |
| 10 | Switching diode | `1N4148W` | Flyback diode across each relay coil |
| 10 | 1 kΩ resistor, 1206 | any 1% 1206 (e.g. [1206 chip-resistor kit, 0R–10M, 72 values](https://www.amazon.com/dp/B0DF74GXKL)) | Transistor base resistor |
| 11 | 10 kΩ resistor, 1206 | any 1% 1206 | Base pulldowns (10), MCP23017 `~RESET` pull-up R23 (1) |
| 1 | Microchip MCP23017, SOIC-28 | `MCP23017-E/SO` | I²C GPIO expander for relay controls, 0x20 |
| 1 | Integrated 2.8" ESP32 touch TFT | "Cheap Yellow Display", ESP32-2432S028R family, e.g. [ELEGOO ESP32 2.8" touch display, 240×320 ILI9341, USB-C](https://www.amazon.com/dp/B0FJQ6RK39) | UI, USB, controller |

### 11.3 Decoupling / power

| Qty | Part | Mfr. part number | Function / notes |
|---:|---|---|---|
| 2 | 100 nF, 16 V, X7R, SMD | `SH31B104K160CT` | Decoupling at the MCP23017 (C1) and the TMP275 (C2) |
| 2 | 22 µF, 1206 MLCC | `EMK316BB7226ML-T` | Bulk decoupling at the power entry (C3, C4) |
| 2 | 4.7 kΩ resistor, 1206 | any 1% 1206 | SDA/SCL pull-ups to 3V3 |

### 11.4 Front panel / mechanical

| Qty | Item | Notes |
|---:|---|---|
| 4 | Female banana jacks, 2 red + 2 black | NORMAL IN + / − and OUT + / −. e.g. [Amazon B07C7WG23G](https://www.amazon.com/dp/B07C7WG23G) |
| 1 | Enclosure | 3D-printed: front panel, back panel, base plate, cover, PCB holder (SOLIDWORKS, STEP and 3MF in `enclosure/`). The front panel also serves as the TFT bezel. Print settings: see the README |
| 1 | Banana-jack nut wrench | 3D-printed tool (`enclosure/banana-plug-wrench-v0`) for the banana-jack nuts |
| 3 | JST 1.25 mm 4-pin male plug, 100 mm pigtail, 26 AWG | Display-module harnesses. e.g. [Amazon B0DMT2GBZH](https://www.amazon.com/dp/B0DMT2GBZH) |
| 1 | 1 ft USB-to-USB extension cable | Brings the module's USB out to the back panel. e.g. [Amazon B0GRVZ62VR](https://www.amazon.com/dp/B0GRVZ62VR) |

The display-module pigtails solder straight to the `J7`/`J8` pads; there are no board-side headers.

### 11.5 Fasteners

| Qty | Item | Use |
|---:|---|---|
| 4 | M2×4 machine screw | PCB to PCB holder |
| 4 | M2 flat washer | PCB to PCB holder |
| 4 | M2×4×3.2 knurled brass heat-set insert | Heat-set into the PCB holder, takes the PCB screws |
| 4 | M3×6 button-head socket screw | Display module (CYD) mounting |
| 4 | M3 nut | Display module (CYD) mounting |
| 14 | M3×8 button-head socket screw | Enclosure assembly |
| 14 | M3×4×4.2 knurled brass heat-set insert | Heat-set into the printed enclosure parts, take the assembly screws |
| 2 | M2×12 machine screw | USB extension cable mount |
| 2 | M2 flat washer | USB extension cable mount |
| 2 | M2 nut | USB extension cable mount |

Totals: M2×4 screws ×4, M2×12 screws ×2, M2 washers ×6, M2 nuts ×2, M2×4×3.2 inserts ×4;
M3×6 button-head ×4, M3×8 button-head ×14, M3 nuts ×4, M3×4×4.2 inserts ×14.

---

## 12. Design principles

1. **Do not synthesize nanovolts directly.** Generate ordinary voltages well and attenuate them.
2. **Keep the precision signal path passive.**
3. **Nothing switches below the 1 Ω measurement node.**
4. **A zero measurement preserves the same low-voltage path.**
5. **Use latching relays so coil power and heating vanish during measurement.**
6. **Separate digital/warm electronics physically from the precision divider.**
7. **Calibrate actual ratios; do not depend on nominal resistor tolerance.**
8. **Measure temperature before attempting temperature correction.**
9. **Favor simple, inspectable circuitry over unnecessary analog sophistication.**
10. **Keep the instrument single-purpose.** A capability that has to share the 1 Ω low leg inherits its
    constraints; if those make it a poor version of the thing, it belongs in its own box.

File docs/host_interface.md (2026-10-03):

# Host interface

What a program driving the divider over USB needs to know: the link, the one trap in opening it,
how to detect a controller reset, grounding, and the SCPI contract. The full command reference is in
[`firmware/README.md`](../firmware/README.md). The examples use Linux on a Raspberry Pi, which is
how the instrument is run, but nothing here is specific to it.

## 1. Link

| | |
|---|---|
| Physical | The display module's USB port (CH340, VID:PID `1a86:7523`). It also powers the instrument, including the relay coils: 40 mA pulses, one at a time. |
| Serial | 115200 8N1, no flow control. Commands end in `\n`, and so do responses. |
| Device name | The CH340 has no serial number, so the USB port position is its identity. Use a `by-path` udev symlink and keep the cable in the same port (rule below). |
| Unsolicited output | Lines starting with `# ` (hash, space): the boot banner, `# ready`, and `DIAG:TRAC` pulse traces. Skip them. A definite-length block starts with `#` followed by a digit, so the two never collide. |
| Radio | Never initialised. USB is the only control path. |

A udev rule that names the port and clears HUPCL (see below), with `ID_PATH` taken from
`udevadm info -q property -n /dev/ttyUSB0`:

```
# /etc/udev/rules.d/99-nvdivider.rules
SUBSYSTEM=="tty", ATTRS{idVendor}=="1a86", ATTRS{idProduct}=="7523", ENV{ID_PATH}=="<path>", SYMLINK+="nvdivider", RUN+="/bin/stty -F /dev/%k -hupcl"
```

### Reset on open: the one trap

The module's auto-reset circuit pulls the ESP32's EN low while **RTS is asserted and DTR is not**. A
reset re-runs the boot safe state (all relays to RESET, i.e. ISOLATE), which in the middle of a
measurement is a silent change of stimulus.

* **On Linux**, `open()` asserts both lines, and pyserial then applies its `dtr` setting before its
  `rts` setting. Opening with `dtr=False, rts=False` therefore passes through "RTS only" and resets the
  board. **Open with both left asserted** (`dtr=True, rts=True`, pyserial's default), so no line ever
  changes.
* **On Windows** both lines are applied together at open, and released/released is safe.
  `tools/scpi.py` handles both platforms.
* **Clear HUPCL** (`stty -hupcl`, the udev rule above), so that closing the port does not drop the lines
  either.

Verified on a Raspberry Pi: with the above, 100 open/close cycles left `SYST:BOOT:COUNT?` unchanged and
`SYST:UPT?` counting. **Verify it on any new host**: read the boot count, open and close the port 100
times, read it again. It must not change.

If the circuit cannot be tamed on some host, the hardware fallback is to lift the RTS-to-EN transistor on
the module. Flashing then needs the BOOT button held.

### Reset detection

Even with the above, a long run must detect a reboot rather than assume there was none. Causes include
brown-out, watchdog, or someone pressing the button.

* `SYST:BOOT:COUNT?` is an NVS counter, incremented on every boot. Record it at start and check it
  regularly. It is also the last field of `SYST:MODE?` (`BOOT=n`), so one query per poll covers state
  and reboots together.
* `SYST:UPT?` gives seconds since boot.
* **On a change:**
  1. mark the affected samples;
  2. re-send `SYST:TIME` (the clock is RAM-only);
  3. re-assert the wanted state with explicit commands.

  The host owns the desired state. The firmware deliberately has no "resume" mode.

### Grounds

`DGND`, the control ground, is tied through USB to the host, and possibly through the host to the
meter's chassis (e.g. via a GPIB adapter). The precision path (NORMAL IN, the high legs, the 1 Ω,
OUT) is galvanically separate: it touches the control side only through relay contacts, and the coil
drivers sit on the far side of the relay's coil-contact isolation. No loop is introduced through the
analog path. Keep the meter's LO on OUT− as the only connection between the measurement and anything
grounded.

## 2. SCPI contract

* **Error queue.** Errors never appear in the response stream; they queue for `SYST:ERR?`
  (`0,"No error"` when clean). **After every write, drain `SYST:ERR?` and raise on anything
  non-zero.** A rejected command changes nothing. That includes `CAL:REC`, which checks every field
  before touching the record.
* **Synchronisation.** Commands execute in order, and a query blocks until everything before it has
  finished. Append `;*OPC?` to a write to wait for completion.
* **Timing.** A coil pulse takes 20 ms plus a 20 ms gap.

  | Command | Pulses | Time |
  |---|---|---|
  | `OUTP` | 1 | 40 ms |
  | `POL` (while injecting) | 3 | 120 ms |
  | `RANG` (while injecting) | 4 | 160 ms |
  | `*RST` | 5 | 200 ms |

  `OUTP OFF` pulses even when already isolated, so a host that re-asserts state should command only
  what differs. SD operations take 50 to 300 ms. A 64 KiB `MMEM:DATA?` chunk takes about 6 s at
  115200 baud.
* **Not a number.** `9.91E+37` stands for "no value": no range selected, or no temperature.

| Need | Command | Response |
|---|---|---|
| Identify | `*IDN?` | `NVD,Nanovolt Divider Rev A,<efuse MAC>,<fw version>` |
| Whole state | `SYST:MODE?` | `BOARD=OK,STATE=KNOWN,RANGE=1E-6,POL=NORM,OUTP=INJECT,TEMP=23.8125,FACTOR=…,CAL=SAVED,LOG=OFF,BOOT=5` |
| Set state | `RANG 1E-5\|1E-6\|1E-7\|NONE`, `POL NORM\|INV`, `OUTP ON\|OFF`, `*RST` | Break-before-make and isolate-while-switching are enforced by the firmware. |
| Temperature | `TEMP?` | °C, 4 decimals (TMP275, 1/16 °C steps, refreshed at 1 Hz) |
| Factor now | `SOUR:FACT?` | Active range at the live temperature. |
| Factor at T | `CAL:FACT? <range>[,<T>]` | `k,u_ppm,in_span`. T defaults to live. `in_span=0` outside [Tmin, Tmax] or with no temperature. |
| Calibration | `CAL:REC <range>,k0,T0,alpha,beta,u_k0_ppm,u_alpha_ppm,Tmin,Tmax,"date","source"`, `CAL:REC? <range>`, `CAL:SAVE`, `CAL:EXP` | See [calibration.md](calibration.md), "Write-back". `CAL:REC?` returns the fields without the range. |
| Clock | `SYST:TIME <unix s>`, `SYST:TIME?` | UTC, RAM only, 0 = unset. Set it on every connect. |
| Reset detection | `SYST:BOOT:COUNT?`, `SYST:UPT?` | |
| Files | `MMEM:CAT? ["/nvd"]`; `MMEM:DATA? "<path>"[,offset[,length ≤ 65536]]` | `"name",size,…`; an IEEE 488.2 block `#<n><len><bytes>` followed by `\n`. `MMEM:DATA?` must be the only command on its line. `tools/scpi.py` `Instrument.fetch()` is a reference implementation of chunked reads. |

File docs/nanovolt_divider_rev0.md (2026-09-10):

# Programmable Nanovolt Divider / Precision Attenuator
## Rev0 Design Specification

**Revision:** Rev0  
**Date:** 2026-09-06  
**Status:** Architecture locked; schematic and PCB layout next  
**Primary use:** calibrated low-level DC injection and sub-LSB metrology with an external precision DMM  
**Scope note:** a second, passive path for measuring a ~450 V Geiger-counter supply was specified for Rev0 and then removed - see §4.3.

---

## 1. Problem statement

The goal is to build a compact bench instrument that converts an ordinary, controllable DC source into a stable and calibrated nanovolt-to-microvolt signal by **passive resistive attenuation**, rather than attempting to synthesize nanovolts directly.

The motivating experiment used a LAN-controlled bench power supply, a simple ~1:10^6 divider built from inexpensive resistors, an HP 3478A 5½-digit DMM on its 30 mV range, and ABBA modulation/averaging. That setup demonstrated reliable recovery of signals well below the DMM's 100 nV quantization count, including signals around 20 nV.

The Rev0 instrument should preserve the simplicity of the successful experiment:

> **A conventional voltage source + passive precision attenuation + reversal + true zero + calibration + averaging.**

The precision signal path should remain as passive and electrically quiet as practical.

---

## 2. Planned capabilities

1. **Three programmable normal-input attenuation ranges**
   - approximately `1e-5`
   - approximately `1e-6`
   - approximately `1e-7`

2. **Shared 1 Ω low-leg resistor**
   - permanent part of the DMM measurement path
   - never switched out of the low-voltage path
   - serves as the "heart" of the divider

3. **Programmable polarity reversal**
   - implemented with a latching relay
   - reversal occurs upstream of the precision divider

4. **Programmable injection / isolation**
   - implemented with a latching relay upstream of the 1 Ω resistor
   - `INJECT`: selected source drives current through the 1 Ω resistor
   - `ISOLATE`: high-side source is disconnected while the DMM remains connected across the same 1 Ω resistor
   - provides a physically meaningful zero without perturbing the low-voltage measurement path

5. **~~Dedicated high-voltage input~~** — *removed, see §4.3*

6. **Temperature monitoring**
   - one TMP275 located adjacent to the 1 Ω resistor
   - used to characterize thermal behavior and support optional ratio correction
   - SOIC-8, because the board is hand-soldered; the TMP117 it replaced is DSBGA-6 only
   - ±0.5 °C / 12-bit rather than the TMP117's ±0.1 °C / 16-bit. The correction is driven by the
     *change* in temperature since calibration, so short-term repeatability matters here and
     absolute accuracy does not.

7. **Stored calibration**
   - calibrated divider multiplier for each normal range
   - reference temperature
   - optional measured temperature coefficient for each range
   - calibration metadata stored in nonvolatile memory

8. **Local user interface**
   - integrated 2.8" ESP32 + 320×240 resistive-touch TFT module
   - touchscreen control of:
     - range
     - polarity
     - injection/isolation
   - display shows active mode, range, polarity, output state, calibrated factor, temperature, and communications status

9. **Remote control**
   - SCPI-style command interface over USB serial
   - SCPI-style command interface over Wi-Fi/TCP
   - USB and Wi-Fi use the same internal parser/state machine

---

## 3. Rev0 non-goals

Rev0 intentionally avoids becoming a general-purpose precision source or full HV instrument.

Not planned for Rev0:

- direct nanovolt generation with DACs/op-amps
- precision voltage reference
- closed-loop output regulation
- internal DMM/ADC as the metrology reference
- automatic PSU control inside the instrument
- sub-nanovolt absolute-accuracy claims
- complex active analog circuitry in the precision signal path

The external PSU remains the voltage source; the external DMM remains the measurement reference.

---

## 4. Electrical architecture

### 4.1 Normal-input signal path

The normal input uses five identical dual-coil latching relay channels:

| Relay | Function |
|---|---|
| K1 | Select 100 kΩ high leg (`~1e-5`) |
| K2 | Select 1 MΩ high leg (`~1e-6`) |
| K3 | Select 10 MΩ high leg (`~1e-7`) |
| K4 | Polarity reversal |
| K5 | Injection enable / isolation |

Only one range relay is active at a time.

Nominal divider factors are:

\[
k = \frac{R_L}{R_H + R_L}
\]

with \(R_L = 1\ \Omega\).

| Range | High leg | Nominal factor |
|---|---:|---:|
| `1e-5` | 100 kΩ | 9.999900001e-6 |
| `1e-6` | 1 MΩ | 9.999990000e-7 |
| `1e-7` | 10 MΩ | 9.999999000e-8 |

Actual factors will be determined by calibration and stored in firmware.

### 4.2 Zero / isolation philosophy

The 1 Ω low-leg resistor is **never shorted and never removed from the DMM path**.

In `INJECT` mode:

```text
selected high leg -> injection node -> 1 Ω -> analog return
                                  |           |
                                DMM HI      DMM LO
```

In `ISOLATE` mode:

```text
selected high leg -> OPEN

                    injection node -> 1 Ω -> analog return
                         |                    |
                       DMM HI               DMM LO
```

This preserves the same 1 Ω resistor, PCB traces, solder joints, output connector, cable, and DMM terminals. Only the intentionally injected current is removed.

### 4.3 High-voltage path — removed

Rev0 originally carried a second passive input for a ~450 V Geiger-counter supply: a dedicated
10 MΩ high leg into the **shared** 1 Ω low leg, selected by a physical 3PDT NORMAL/HV toggle. It
has been removed. The reasoning is recorded here because the numbers are the useful part:

- Sharing the 1 Ω leg capped the ratio. At 10 MΩ the divider drew 45 µA and delivered **45 µV**
  out; more output meant a smaller high leg, and 1 MΩ draws 450 µA where 10 MΩ draws 45 µA.
- A Geiger supply is built to source microamps into a tube that draws almost none, so its output
  impedance is high — often set by a deliberate series anode resistor. Against a 1 MΩ source
  impedance a 10 MΩ divider already reads 9 % low, and a 1 MΩ divider reads 50 % low. That error
  tracks the supply's operating point, so calibration cannot remove it.
- The HV path had **no polarity reversal** — K4 serves the NORMAL input only — so thermal EMF and
  DMM offset could not be nulled by ABBA the way they are on the normal ranges. More output was
  exactly what that path needed, and the shared 1 Ω leg was the one thing that would not give it.

A dedicated fixed divider is free of all three constraints, because it chooses its own low leg. The
450 V measurement therefore moves out of this instrument, and Rev0 stays single-purpose.

Removed with it: `R34`, `J3`, `SW1` and the panel toggle, `R24`/`R25`/`C5`, the `J9`/P3 harness,
the `HV` netclass and its clearance/creepage rules, and 11 mm of board height. `SW1`'s two analog
poles were only ever selecting between the normal path and the HV path, so with the HV path gone
both collapse to plain nets: K5's `A_NO` lands directly on `MEAS_NODE` and its `B_NO` directly on
`ANALOG_RTN`. The ISOLATE function is untouched — K5 was always what performed it.

---

## 5. System block diagram

```mermaid
flowchart LR
    subgraph CTRL["Front / Control Section"]
        UI["2.8 in ESP32 Touch TFT"]
        IO["MCP23017\nI²C GPIO expander"]
        T["TMP275\ntemperature sensor"]
        UI <-->|I²C / control| IO
        UI <-->|I²C| T
    end

    subgraph NORMAL["Normal Precision Divider"]
        NIN["NORMAL IN\n+ / -"]
        POL["K4\nPOLARITY"]
        RSEL["K1 / K2 / K3\nRange select"]
        RH["100 kΩ / 1 MΩ / 10 MΩ"]
        INJ["K5\nINJECT / ISOLATE"]
        NIN --> POL --> RSEL --> RH --> INJ
    end

    NODE["Measurement node"]
    RL["1 Ω precision low leg"]
    OUT["DIVIDER OUT\n+ / -"]

    NORMAL --> NODE --> RL --> OUT

    IO -. "10 relay-coil control lines" .-> NORMAL
    T -. "thermal proximity only; no analog connection" .-> RL
```

---

## 6. Control architecture

### 6.1 Controller

Rev0 uses an integrated **2.8" ESP32 touch-display module** rather than a separate Arduino + TFT.

Expected module characteristics:

- ESP32 MCU
- Wi-Fi
- USB serial interface
- 320×240 ILI9341 TFT
- resistive touchscreen / XPT2046-type controller

### 6.2 GPIO expansion

Five TQ2-L2 relays require ten coil-control outputs:

- 5 × SET
- 5 × RESET

An **MCP23017** I²C GPIO expander provides these outputs.

The ten MCP23017 outputs drive ten identical low-side transistor stages:

```text
MCP23017 GPIO
    |
   1 kΩ
    |
MMBT2222A base
    |
10 kΩ pulldown to DGND

relay coil -> MMBT2222A collector
MMBT2222A emitter -> DGND
1N4148W flyback diode across relay coil
```

The same I²C bus is used for the TMP275 (address 0x48, `A2`/`A1`/`A0` all on `DGND`).

### 6.3 Relay safety/state rules

1. Power-up into a deterministic safe state.
2. Establish `ISOLATE` before configuring other relay states.
3. Only one range relay may be active at a time.
4. Range changes use break-before-make.
5. Polarity changes occur while isolated.
6. Relay coils are pulsed only briefly; they are never continuously energized.

---

## 7. Mechanical / thermal architecture

The enclosure should have two physically distinct regions.

### Control / warm / noisy region

- ESP32 + touchscreen
- Wi-Fi antenna
- MCP23017
- relay-driver electronics
- USB/power wiring

### Precision / quiet region

- relay contacts
- precision high-leg resistors
- 1 Ω resistor
- TMP275
- output connector

A physical divider wall inside the enclosure is desirable for airflow isolation, thermal isolation, and wiring organization.

The enclosure should not be fully metallic because the ESP32 Wi-Fi antenna requires an RF-transparent path. A plastic-bodied instrument enclosure with a machinable metal front panel is preferred.

### 1 Ω thermal region

The 1 Ω resistor should receive special layout treatment:

- located near the output connector,
- minimal low-level trace length,
- output/sense traces branch directly from the resistor terminals,
- TMP275 placed nearby,
- no relay coil or TFT/backlight heat nearby,
- optional PCB cutouts/slots to reduce thermal conduction from the rest of the board.

---

## 8. Calibration model

Each range stores a calibration record:

```text
RangeCalibration
    range_id
    nominal_factor
    calibrated_factor_at_Tref
    reference_temperature
    measured_ratio_tempco
    calibration_timestamp
```

Temperature correction, once characterized, may use:

\[
k(T) = k_0 \left[1 + \alpha(T - T_0)\right]
\]

Rev0 firmware should support the field from the beginning but use **zero temperature correction until the coefficient is experimentally measured**.

---

## 9. Planned SCPI interface

Exact command names may evolve, but Rev0 should support these concepts:

```text
*IDN?
*RST?

:OUTP ON
:OUTP OFF
:OUTP?

:POL NORM
:POL INV
:POL?

:RANG 1E-5
:RANG 1E-6
:RANG 1E-7
:RANG?

:TEMP?

:CAL:RATIO?
:CAL:TC?
:CAL:TREF?

:SOUR:FACTOR?
:SYST:MODE?
```

USB serial and Wi-Fi/TCP should share the same parser and instrument state machine.

---

## 10. KiCad schematic organization

The schematic should be created **top-down**.

Recommended hierarchy:

```text
nanovolt-divider.kicad_sch        # root / system architecture
|
+-- control.kicad_sch
|     ESP32/display interface
|     MCP23017
|     TMP275 interface
|     power/decoupling
|
+-- relay_channel.kicad_sch       # same file instantiated 5 times
      K1 RANGE_1E5
      K2 RANGE_1E6
      K3 RANGE_1E7
      K4 POLARITY
      K5 INJECT
```

The root sheet owns the actual metrology topology:

- NORMAL input
- 100 kΩ / 1 MΩ / 10 MΩ divider network
- 1 Ω low leg
- output terminals

`relay_channel.kicad_sch` should be generic and expose:

```text
SET
RESET

A_COM
A_NO
A_NC

B_COM
B_NO
B_NC
```

The same sheet is instantiated five times. KiCad's multi-channel/repeat-layout workflow can then duplicate the physical relay-driver layout after one channel is placed and routed.

---

## 11. BOM — Rev0

### 11.1 Precision / analog components

| Qty Rev0 | Part | Mfr. part number | Function / notes | Status |
|---:|---|---|---|---|
| 1 | Vishay/Dale 1 Ω wirewound | `RS02C1R000FE70` | Shared low leg, 1%, 2.5 W, through-hole | **Purchased** |
| 1 | Ohmite 100 kΩ metal film | `MOX70031003BZE` | Normal `1e-5` range, 0.1%, 5 ppm/°C | **Purchased** |
| 1 | Ohmite 1 MΩ metal film | `MOX70031004BYE` | Normal `1e-6` range, 0.1%, 10 ppm/°C | **Purchased** |
| 1 | Ohmite 10 MΩ thick film | `SM102031005FE` | Normal `1e-7` range, 1% | **Purchased** |
| 5 | Panasonic latching relay | `TQ2-L2-5V-3` | K1–K5 | 1 purchased; **4 more required** |
| 1 | TI temperature sensor, SOIC-8 | `TMP275AIDR` | Temperature of 1 Ω region, I²C 0x48 | **To order** (the purchased `TMP117MAIYBGR` is DSBGA-6 and cannot be hand-soldered) |

### 11.2 Relay-driver / control-board components

| Qty Rev0 | Part | Mfr. part number | Function / notes | Status |
|---:|---|---|---|---|
| 10 | NPN transistor, SOT-23 | `MMBT2222A` | Two low-side coil drivers per relay | **12 purchased** |
| 10 | Switching diode | `1N4148W` | Flyback diode across each relay coil | **12 purchased** |
| 10 | 1 kΩ resistor, 1206 | existing stock/library | Transistor base resistor | On hand / source TBD |
| 10 | 10 kΩ resistor, 1206 | existing stock/library | Base pulldown | On hand / source TBD |
| 1 | MCP23017 | TBD | I²C GPIO expander for relay controls | **To order** |
| 1 | Integrated 2.8" ESP32 touch TFT | ELEGOO / ESP32 2.8" ILI9341-type module | UI, Wi-Fi, USB, controller | Planned / status TBD |

### 11.3 Decoupling / power

| Qty Rev0 | Part | Mfr. part number | Function / notes | Status |
|---:|---|---|---|---|
| as needed | 100 nF, 16 V, X7R, SMD | `SH31B104K160CT` | Local high-frequency decoupling | **20 purchased** |
| 2–3 | 22 µF, 1206 MLCC | `EMK316BB7226ML-T` | Local/bulk 5 V decoupling | **3 purchased** |
| 2 | I²C pull-up resistors, 1206 | TBD | SDA/SCL pull-ups if required | On hand / TBD |

### 11.4 Front panel / mechanical

| Qty | Item | Notes | Status |
|---:|---|---|---|
| 2 | Normal-input banana sockets | + / − | To select |
| 2 | Output banana sockets | + / − | To select |
| 1 | Stock instrument enclosure | RF-transparent body preferred, machinable metal front panel | TBD |
| 1 | Internal compartment divider | Plastic / FR4 / 3D printed | To design |
| 1 | TFT mounting bezel | Optional 3D-printed bezel | To design |
| misc. | PCB standoffs, harnesses | Mechanical integration | TBD |
| - | *(no board-side harness headers)* | Display-module pigtails solder straight to `J7`/`J8`/`J9` pads | n/a |

---

## 12. First Mouser order

The first Mouser order establishes the core passive-divider and relay-driver component set:

- 1 Ω low-leg resistor
- 100 kΩ, 1 MΩ, and 10 MΩ divider resistors
- 12 × MMBT2222A
- 12 × 1N4148W
- 20 × 100 nF X7R MLCCs
- 3 × 1206 bulk MLCCs
- 1 × TMP117 *(DSBGA-6, superseded - see 11.1)*
- 1 × TQ2-L2-5V-3 relay

Additional Rev0 procurement is expected to include:

- four more TQ2-L2-5V-3 relays,
- one `TMP275AIDR` (SOIC-8) in place of the DSBGA-6 TMP117,
- MCP23017,
- banana sockets,
- enclosure/mechanical hardware.

---

## 13. Rev0 design principles

1. **Do not synthesize nanovolts directly.** Generate ordinary voltages well and attenuate them.
2. **Keep the precision signal path passive.**
3. **Nothing switches below the 1 Ω measurement node.**
4. **A zero measurement should preserve the same low-voltage path.**
5. **Use latching relays so coil power and heating vanish during measurement.**
6. **Separate digital/warm electronics physically from the precision divider.**
7. **Calibrate actual ratios; do not depend on nominal resistor tolerance.**
8. **Measure temperature before attempting temperature correction.**
9. **Favor simple, inspectable circuitry over unnecessary analog sophistication.**
10. **Keep the instrument single-purpose.** A capability that has to share the 1 Ω low leg inherits
    its constraints; if those constraints make it a poor version of the thing, it belongs in its own
    box. This is what retired the 450 V path — see §4.3.

---

## 14. Immediate next steps

1. Create the KiCad project and project-local symbol/footprint libraries.
2. Draw the Rev0 root-sheet architecture first.
3. Create the generic `relay_channel.kicad_sch` interface.
4. Instantiate the relay channel five times.
5. Implement and ERC-check one relay channel.
6. Build the control sheet around the ESP32 module, MCP23017, and TMP275.
7. Complete the precision signal path on the root sheet.
9. Assign real footprints from component datasheets.
10. Perform a schematic architecture/safety review before starting PCB placement.

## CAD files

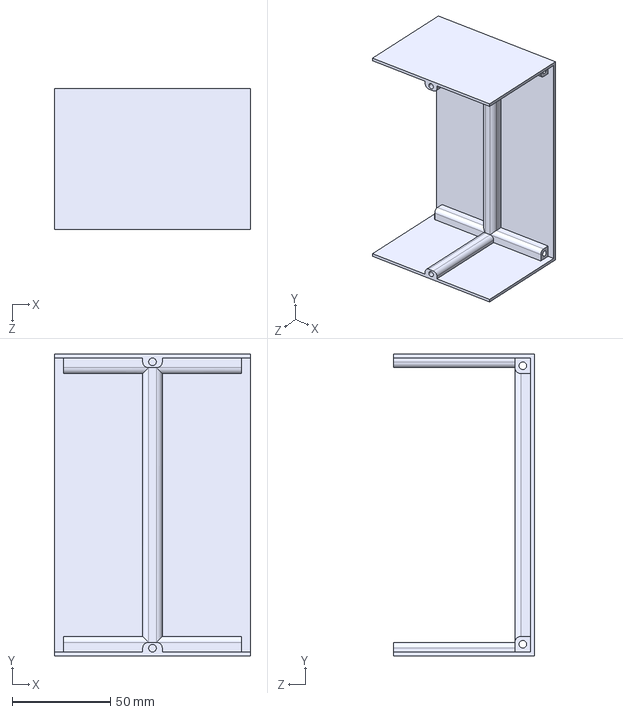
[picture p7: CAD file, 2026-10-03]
enclosure/cover-v1.STEP
100.0 x 154.0 x 72.0 mm

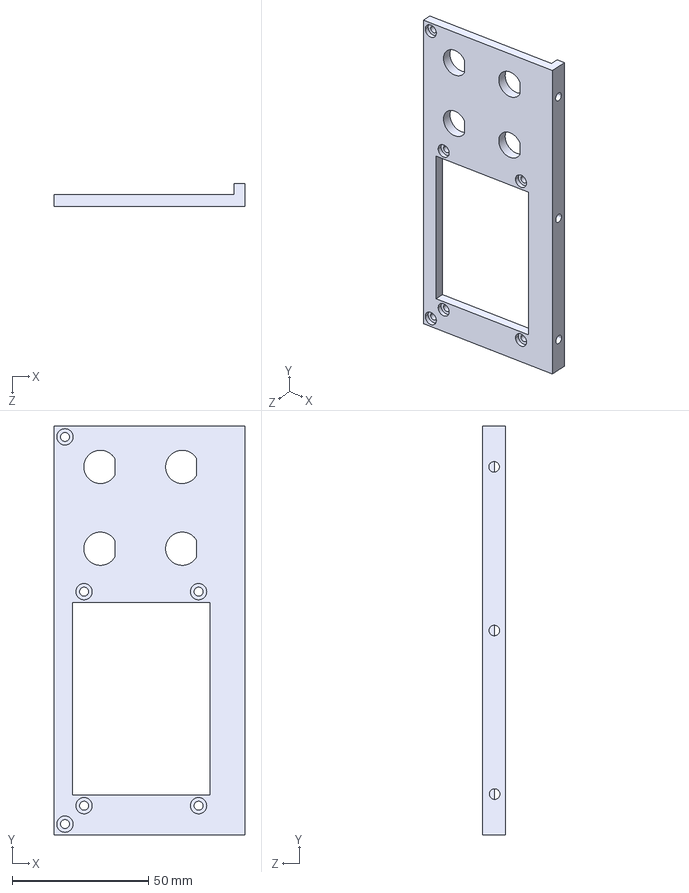
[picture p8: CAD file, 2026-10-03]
enclosure/front-panel-v0.STEP
70.0 x 150.0 x 8.50 mm

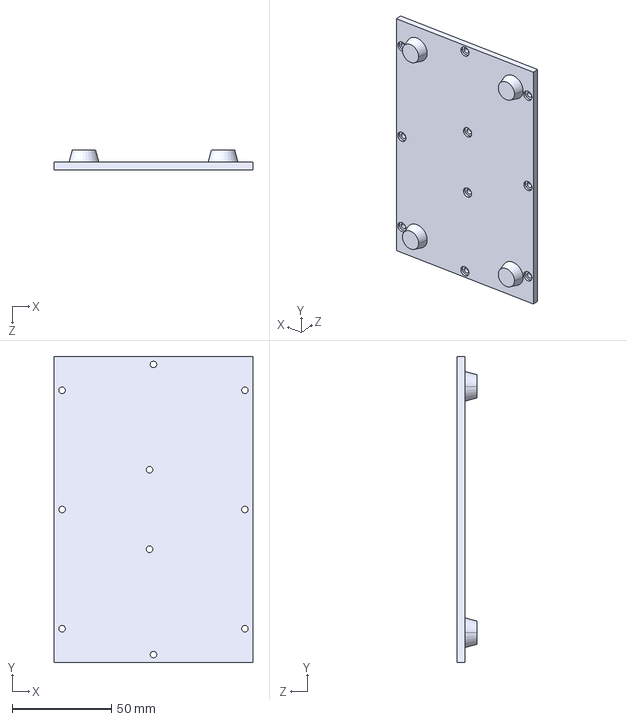
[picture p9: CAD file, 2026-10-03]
enclosure/base-plate-v1.STEP
100.0 x 154.0 x 10.0 mm

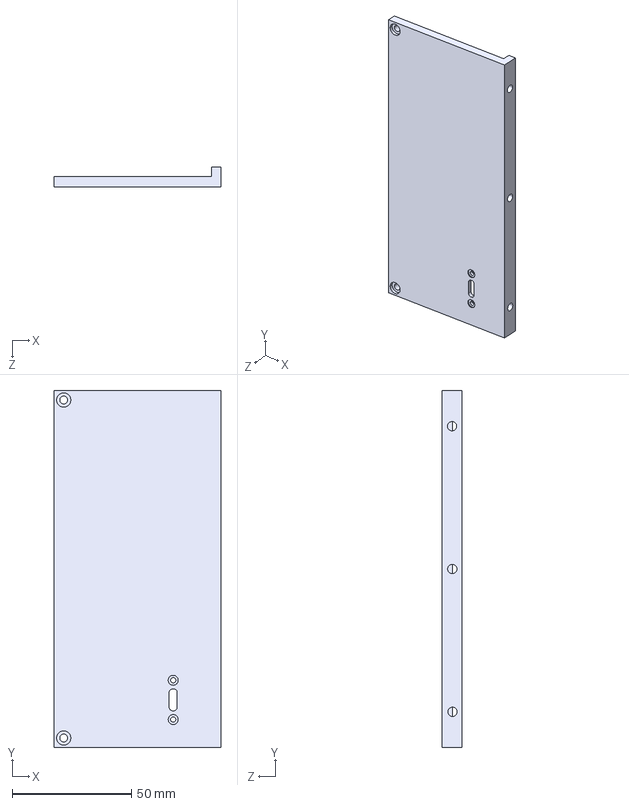
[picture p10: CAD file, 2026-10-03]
enclosure/back-panel-v0.STEP
70.0 x 150.0 x 8.50 mm

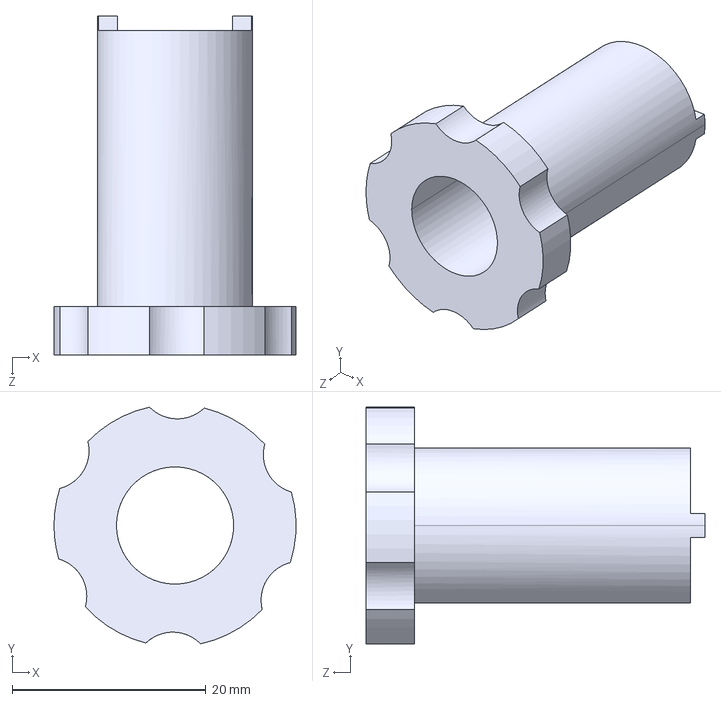
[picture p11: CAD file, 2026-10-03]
enclosure/banana-plug-wrench-v0.STEP
25.0 x 24.4 x 35.0 mm

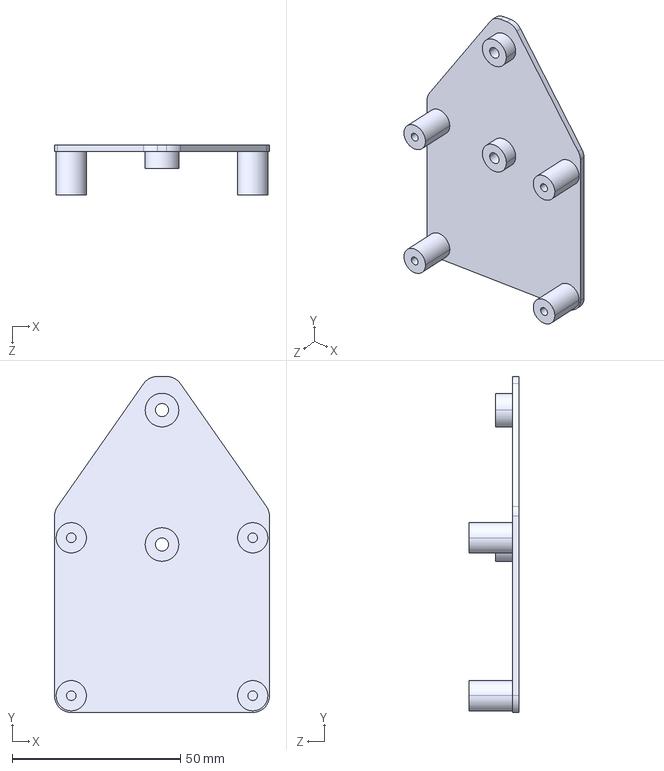
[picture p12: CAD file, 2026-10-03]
enclosure/pcb-holder-v0.STEP
64.0 x 100.0 x 15.0 mm

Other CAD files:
enclosure/back-panel-v0.3MF
enclosure/back-panel-v0.SLDPRT
enclosure/banana-plug-wrench-v0.3MF
enclosure/banana-plug-wrench-v0.SLDPRT
enclosure/base-plate-v1.3MF
enclosure/base-plate-v1.SLDPRT
enclosure/cover-v1.3MF
enclosure/cover-v1.SLDPRT
enclosure/front-panel-v0.3MF
enclosure/front-panel-v0.SLDPRT
enclosure/pcb-holder-v0.3MF
enclosure/pcb-holder-v0.SLDPRT

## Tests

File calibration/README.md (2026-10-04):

# Calibration data

The small, durable data behind each result in [docs/calibration.md](../docs/calibration.md): enough to
check every number there and to compare against your own build. The raw per-sample logs are not
kept here; they run to hundreds of megabytes per step.

One directory per step, named by date and step:

```
calibration/
  YYYY-MM-DD_supply/        step 1
  YYYY-MM-DD_high-legs/     step 2
  YYYY-MM-DD_null/          step 3
  YYYY-MM-DD_ratio/         step 4
  YYYY-MM-DD_injection/     step 5
  records/                  CAL:REC values written to the instrument
```

Each step directory holds:

* `summary.json`: the conditions (instruments, setpoints, duration, TMP275 span), the fitted
  coefficients and their uncertainties.
* Per-dwell or per-block CSV where the result is built from blocks: one row per block with its UTC
  time, range, polarity pattern, mean, scatter, sample count and TMP275 reading.
* The figures used in the results section.
* `analyze.py`: the script that produced them from the raw logs, so the method is exact.

**Reproduce** a step's fits and figures from its published 1-minute data, for example step 1:

```
cd calibration/2026-09-27_supply
uv run --with numpy --with matplotlib --with polars --with tzdata python analyze.py --minute minute.csv out
```

`out/summary.json` matches the published one, except `samples`: from the CSV it counts only the
samples inside the 1-minute means.

All timestamps are UTC (ISO 8601). Temperatures are TMP275 readings in °C. Voltages are in volts and
resistances in ohms unless a column name says otherwise.

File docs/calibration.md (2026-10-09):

# Calibration

How the divider's three ratios, and their temperature dependence, are measured, how well, and how
the result is written into the instrument. Results are added here as each step completes, so the
page also serves as a reference for anyone building and calibrating their own.

**Status: in progress.** Until calibration completes, the instrument carries nominal records:
k0 = 1/(R_H + 1 Ω), no temperature correction, and u_k0 from the part tolerances (10050 / 10050 /
14142 ppm).

| Step | What it yields | Status |
|---|---|---|
| 1. [Supply characterisation](#1-supply-characterisation) | Supply tempco (as read by the meter), lag and drift; the residual the ratio run inherits | **Done** 2026-10-03, [result](#supply-characterisation-2026-09-27--10-03) |
| 2. [High legs by resistance](#2-high-legs-by-resistance) | R_total per range; the R_L consistency check | **Done** 2026-10-04, [result](#high-legs-by-resistance-2026-10-04) |
| 3. [Null tests](#3-null-tests) | Any signal produced by switching alone | (b) **done** 2026-10-05, [result](#null-test-b-input-shorted-2026-10-04--05); (a) **done** inside the ratio run, [result](#ratio-run-2026-10-05--08); (c) optional, not yet run |
| 4. [Ratio run](#4-ratio-run) | k0 and α per range | **Done** 2026-10-08, [result](#ratio-run-2026-10-05--08); R_L check open |
| 5. [End-to-end injection](#5-end-to-end-injection) | Acceptance: known nanovolt signals recovered | Pending |
| [Write-back](#write-back) | Records stored in the instrument | Pending |

## Equipment

* **Source:** a programmable bench supply (here a UNI-T UDP3305S-E, CH1), output on and constant for
  the whole of every run, current limit 10 mA. The divider draws at most 290 µA (29 V into 100 kΩ).
* **Meter:** one 5½-digit DMM (here an HP 3478A), DC volts, autozero on, a fixed range per run:
  **30 V** at the NORMAL IN jacks, **30 mV** at the OUT jacks.
* **Temperature:** the divider's own TMP275. The supply, meter and divider share a bench, so it is also
  the bench thermometer. There is no temperature chamber: temperature varies only with the room.
* **Host:** a computer logging every meter sample with a UTC timestamp, and every divider transition
  with the time it actually happened ([host_interface.md](host_interface.md)).

## What is calibrated

Per range i ∈ {1E-5, 1E-6, 1E-7}, the instrument stores (`CAL:REC`):

```
k_i(T) = k0_i · [1 + α_i (T − T0) + β_i (T − T0)²]        valid for Tmin ≤ T ≤ Tmax
```

* **T is the TMP275 reading,** not room temperature and not a resistor's own temperature. The sensor
  sits on the slotted 1 Ω island next to R35, so it tracks the low leg closely. The high legs sit off
  the island and see the room through a different thermal path, so their lag relative to the TMP275
  is fitted, not assumed zero.
* **Decomposition.** k = R_L/(R_H + R_L) and R_L/R_H ≤ 1e-5, so to better than 0.1 ppm
  **α_i = α_L − α_H,i**. α_L (the 1 Ω) is common to all three ranges; α_H,i belongs to each high leg.
* **β** stays 0 unless the observed span resolves curvature. **[Tmin, Tmax]** is the TMP275 span
  actually observed. Outside it, `CAL:FACT?` still answers but reports `in_span=0`.
* Stored with each record: `u_k0_ppm` and `u_alpha_ppm` (standard uncertainties, k = 1), a date, and
  a `source` string identifying the calibration.

## Method

* **Modulate, using ABBA.** A 3478A's zero sits near −2 µV and wanders by hundreds of nV over minutes.
  Every output measurement is the difference of polarity-reversed dwells ordered N-I-I-N, which
  cancels offset, thermal EMF and linear drift. Per block, S = (N₁ + N₂ − I₁ − I₂)/4.
* **Reverse inside the divider, never at the source.** K4 sits upstream of the high leg, so any
  thermal EMF of K4, K5 or the range-relay contacts is in series with R_H and reaches the output
  divided by ~1/k: at 1E-5, a 1 µV contact EMF becomes 10 pV. Switching the supply's own output
  relay would add an EMF that switches in step with the signal.
* **60 s dwells, first 2 s dropped.** With this meter, the Allan deviation times √τ is flat below
  about 30 s, so 60 s dwells lose nothing per unit time and keep ABBA's linear-drift assumption
  honest. The sample straddling a switch is discarded, and so is the next.
* **Fixed meter ranges** for a whole run, and **UTC timestamps** throughout. `SYST:TIME` is set on the
  divider at every connect, and `SYST:BOOT:COUNT?` is checked every 10 s.
* **The supply stays on between steps.** After switch-on its output settles over about a day; turning
  it off between steps would restart that.
* **V_cal = 29 V.** The statistical error falls as 1/V, and 29 V leaves headroom at the top of the
  meter's 30 V range for the supply's few-mV positive offset.

## Procedure

### 1. Supply characterisation

The divider isolated with no range selected, so the supply is unloaded and the divider dissipates
nothing. The meter on NORMAL IN, 30 V range, supply at 29 V, for 144 h. Fit
V_in = V0 · [1 + γ (T_lagged − T_ref) + δ·t] against the TMP275: γ is the tempco of the supply as
read by the meter on its 30 V range, δ its drift, plus a fitted lag. The meter sits on the same bench,
so its own 30 V tempco is folded into γ; nothing here separates the two. The residual scatter is the supply's short-term noise, which the ratio run
inherits.

The drop between the supply and the IN jacks under the divider's load (0.5–2 ppm on 1E-5) is not
seen here. The ratio run's anchors on IN, taken under load, carry it.

### 2. High legs by resistance

The supply unplugged from NORMAL IN (left on, unloaded), OUT open, and the meter measuring 2-wire
resistance across NORMAL IN while the divider injects on each range in turn. The meter's ohms range
follows the divider: 300 kΩ, 3 MΩ, 30 MΩ. Each range is measured N, I, I, N, so a thermal EMF in the
path shows as R(N) ≠ R(I) and cancels in the mean. About 3 h.

This reads R_total,i = R_H,i + R_L + contacts + leads. 2-wire is enough: 0.5 Ω of leads is 5 ppm of
100 kΩ, below the meter's ohms accuracy. Combined with the ratio run, R_L,i = k_i · R_total,i must
agree across the three ranges, because R_L is one physical part:

| If this disagrees | Likely cause |
|---|---|
| 1E-7 against the other two | leakage across the 10 MΩ leg, or the meter's 30 MΩ range |
| any one range | a contact or wiring fault on that range |
| all three by the same factor | the meter's volts against its ohms |

### 3. Null tests

The ratio-run schedule with nothing to measure, the meter on OUT on its 30 mV range, about 24–30 h
across three variants:

| Variant | Source | Divider | A signal would mean |
|---|---|---|---|
| a | 29 V applied | ISOLATE, K4 still switching | coil pulses, display or USB traffic couple into OUT |
| b | copper link across NORMAL IN | INJECT | the switched path itself produces an offset |
| c | supply connected at 0 V | INJECT | the real source, at zero, is not a zero |

A nanovolt-level bias matters very differently by range: 2 nV is 7 ppm of the 1E-5 signal at 29 V,
70 ppm of 1E-6 and 700 ppm of 1E-7. A bias found here is corrected for in the ratio run.

### 4. Ratio run

The meter on OUT, 30 mV range, supply at 29 V, for 72 h. One cycle, repeated:

```
for range in 1E-5, 1E-6, 1E-7:
    RANG range; OUTP ON
    ABBA block: POL NORM 60 s, POL INV 60 s, POL INV 60 s, POL NORM 60 s
OUTP OFF: ISOLATE dwell 60 s                  (offset / leakage diagnostic)
```

A cycle takes 13 min, about 330 blocks per range in 72 h. k_i(t) = S / V_in(t), with V_in from the
supply model of step 1, pinned by **anchors**: the meter moved to IN (30 V range) under load for
15 min before and after the run. The anchors set the absolute level; the model supplies the shape.
k_i is then fitted against the TMP275 with a first-order lag, giving k0_i and α_i (and β_i only if
significant).

The ratios k_5/k_6 and k_6/k_7 come free from the same blocks. They cancel the common supply level,
and their temperature dependence is α_H,6 − α_H,5 (and α_H,7 − α_H,6), without needing the supply
model. They do not cancel supply variation entirely: the ranges are measured one after another, 4 min
apart, so the supply's movement between those windows stays in each ratio. Step 1's Allan deviation
puts that near 1 ppm per cycle, averaging down over ~330 cycles, far below the 50 and 500 ppm
statistical limits of 1E-6 and 1E-7.

Each range carries current only 4 minutes in every 13. Self-heating with a time constant of minutes
would show as N₁ ≠ N₂ curvature within blocks, which ABBA does not cancel; it is checked for and
modelled if present.

### 5. End-to-end injection

With the calibrated factors stored, inject known signals of 10–100 nV through the divider and recover
them by the same ABBA method. This tests the divider at its actual job.

## Uncertainty

ABBA blocks of 60 s dwells on the 3478A's 30 mV range scatter by about 13 nV (measured in the
null run, step 3). With ~330 blocks per range at 29 V, the statistical limits on k0 are roughly:

| | 1E-5 | 1E-6 | 1E-7 |
|---|---|---|---|
| Signal at 29 V | 290 µV | 29 µV | 2.9 µV |
| k0, statistical | 2.5 ppm | 25 ppm | 250 ppm |

Statistical and bounded systematic terms are combined; terms nothing here can bound are reported
separately:

| Term | Kind | Bounded by |
|---|---|---|
| ABBA scatter | statistical | Scatter of independent sub-runs (not the fit's formal error). |
| Supply model residual; anchor mismatch before vs after | systematic | Step 1 residuals, the two anchors. |
| Lag / hysteresis (warming vs cooling fits) | systematic | Separate fits on warming and cooling segments. |
| TMP275 quantisation (0.0625 °C) | systematic | Its effect on the fitted α. |
| Switching bias | systematic | Step 3. |
| **Meter range-to-range gain, 30 V vs 30 mV** | **unbounded here** | Enters k0 directly, at the meter's accuracy-spec level (hundreds of ppm). Only a second meter or a reference can close it. |
| Meter input-attenuator tempco (30 V range only) | unbounded here | Does not cancel between steps 1 and 4. A few ppm/°C at most. |
| Sensor-to-leg gain mismatch (high legs off the island) | unbounded here | The range-ratio temperature dependence constrains it. |

**Realistic outcome.** k0 is limited by the meter's range-to-range accuracy rather than by statistics,
except perhaps on 1E-7. α resolves on 1E-5 (a few ppm/°C). On 1E-6 and 1E-7 the natural temperature
swing does not resolve α, and it stays at the part tolerances; within a few °C of T0 that
contributes less than those ranges' statistical limits.

## Write-back

Once the analysis is reviewed:

```
SYST:TIME <now>
CAL:REC 1E-5,<k0>,<T0>,<alpha>,<beta>,<u_k0_ppm>,<u_alpha_ppm>,<Tmin>,<Tmax>,"<date>","<source>"
CAL:REC 1E-6,...
CAL:REC 1E-7,...
SYST:ERR?                      -> must be 0 after each CAL:REC (a rejected record changes nothing)
CAL:SAVE                       -> NVS, and appends to /nvd/cal_history.txt
CAL:EXP                        -> /nvd/cal.txt
CAL:REC? 1E-5 / 1E-6 / 1E-7    -> read back and compare against what was sent
```

The `source` field holds up to 63 characters.

**Acceptance.** A failure in any of these is investigated, not written:
1. Each |k0/nominal − 1| is within the part tolerances: 1 % on the 1 Ω plus 0.1 / 0.1 / 1 % on the
   high legs.
2. The range ratios k_5/k_6 and k_6/k_7 agree with the individual k0 values within the budget.
3. R_L derived from each range (step 2) agrees across the three ranges.
4. The before and after anchors agree within the supply model's residual.
5. The null tests show no switching bias, or one that is measured and corrected.
6. The end-to-end injection recovers its known signals within the stated uncertainty.

**Recalibration.** Once a year, after any repair or relay replacement, or if a spot-check disagrees
with `CAL:FACT?` by more than 3u. A spot-check is one 1E-5 ABBA hour plus anchors.
`/nvd/cal_history.txt` keeps every record the instrument has carried; the firmware can only append
to it.

## Results

Each completed step adds a subsection here: its conditions, its numbers with uncertainties and how
they were derived, anything unexpected, and a figure. The data behind each result is in
[`calibration/`](../calibration/).

### Supply characterisation, 2026-09-27 – 10-03

**Conditions.** UNI-T UDP3305S-E CH1 at 29.00 V into NORMAL IN, the divider isolated with no range
selected (no load). HP 3478A across NORMAL IN, 30 V range, 5½ digits, autozero on, 1 Hz. TMP275
polled every 10 s. 144 h; 518,401 readings, none failed; one 33 s gap. TMP275 span 21.8–28.1 °C.
Fits are on 1-minute means. Data, figures and the analysis script:
[`calibration/2026-09-27_supply/`](../calibration/2026-09-27_supply/).

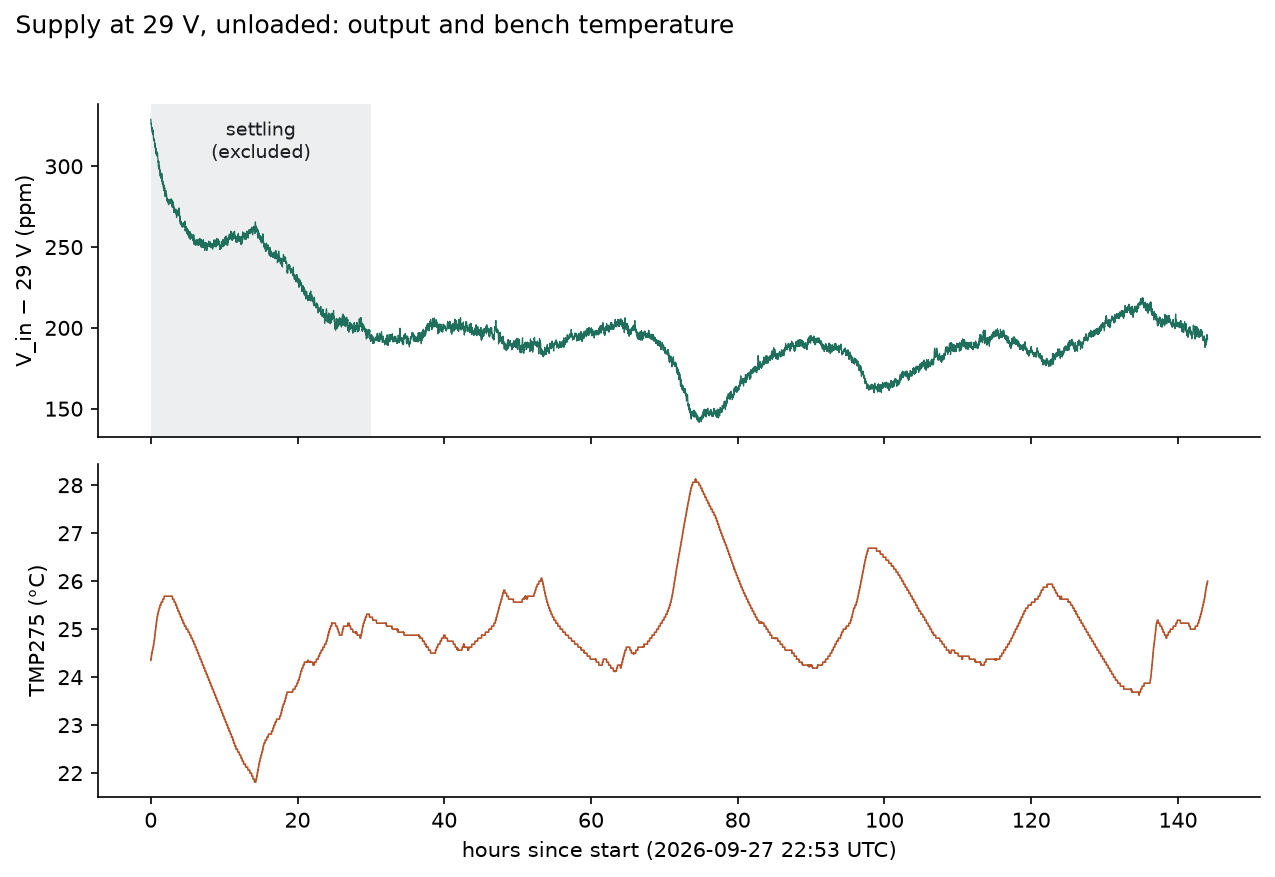
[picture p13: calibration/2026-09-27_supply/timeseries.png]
Supply output and TMP275 over 144 h


**Switch-on settling takes about 30 hours.** The supply came up at 29.0096 V (+330 ppm), fell 119 ppm
(3.4 mV) over the next 30 h, and only then behaved as a function of temperature. Everything below
excludes the first 30 h. Leave the supply on between calibration steps.

**Settled level:** 29.0055 V at 25 °C (+190 ppm above its setpoint), so V_in must be measured, not
taken from the setpoint.

**Tempco.** Model y = a + γ·T_eff + δ·t (y in ppm of 29 V), with T_eff the TMP275 through a lag:

| Fit | γ (ppm/°C) | Lag | Drift (ppm/h) | Residual rms |
|---|---|---|---|---|
| Whole settled span (114 h), first-order lag | −16.1 ± 1.4 | τ = 69 min | −0.02 | 6.4 ppm |
| Day 1 | −12.8 | τ = 57 min | +0.14 | 2.4 ppm |
| Day 2 | −14.5 | τ = 33 min | −0.38 | 2.3 ppm |
| Day 3 | −13.0 | τ = 25 min | +0.20 | 1.8 ppm |
| Day 4 | −10.5 | τ = 20 min | +0.62 | 2.3 ppm |

The ± on the whole-span fit is a jackknife over 6-hour segments, not the fit's formal error, which
assumes independent minutes and is ~10× smaller. Per-day fits each have their own drift term, which
can absorb part of the day's temperature cycle. The whole-span fit has one drift line, so slow level
wander can alias onto the multi-day temperature trend. Both estimates are kept:

> **γ = −14 ± 2 ppm/°C** (−0.41 ± 0.06 mV/°C at 29 V). The supply lags the TMP275 with a first-order
> time constant of roughly 20–70 min, and the lag is not stable from day to day.

γ is the tempco of the supply *and* the HP 3478A's 30 V range together. The meter's input-attenuator
tempco is not bounded independently here (see [Uncertainty](#uncertainty)); it is expected to be a few
ppm/°C at most, but it cannot be separated from the supply's.

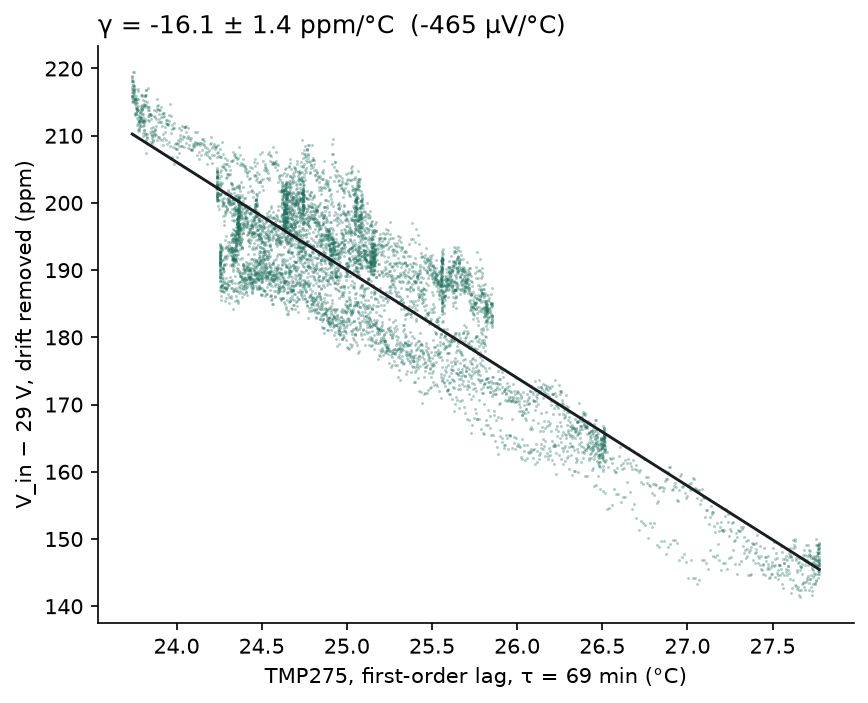
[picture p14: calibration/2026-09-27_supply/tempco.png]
Supply output against the lagged TMP275


**Drift and wander.** Once settled there is no consistent drift (per-day slopes of both signs).
Instead the level wanders: the residual is ~2 ppm rms within a day but 6.4 ppm across days. Its Allan
deviation is flat near 1 ppm (≈ 28 µV) from 1 to 16 min, then rises to 2.6 ppm at 4 h and 4.2 ppm at
17 h.

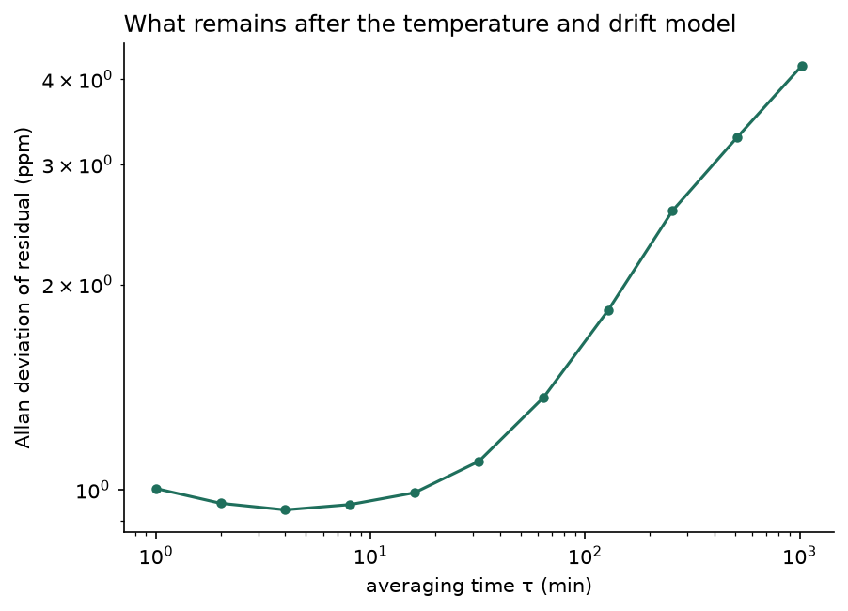
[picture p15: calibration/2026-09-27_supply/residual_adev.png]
Allan deviation of the residual


**What this means for the ratio run.** Over one ABBA block (4 min) the supply contributes about 1 ppm.
Over a 72 h run, a supply model from this step is good to a few ppm over hours and 4–6 ppm over days.
On 1E-5 that is comparable to the statistical limit on k0, and it is well below the meter's
range-to-range gain term. α on 1E-5 inherits about ±2 ppm/°C from γ, plus whatever part of γ is the meter's 30 V tempco
rather than the supply's. The before-and-after anchors on IN
pin the level; a mid-run anchor would bound the multi-day wander.

### High legs by resistance, 2026-10-04

**Conditions.** Supply unplugged from NORMAL IN, OUT open. HP 3478A in 2-wire ohms across NORMAL IN
at 1 Hz, its range following the divider (300 kΩ / 3 MΩ / 30 MΩ), each range measured N, I, I, N per
12-minute cycle; 15 cycles, 3 h. 10,800 readings, none failed (74 retried: the reading that straddles
each polarity change is over-range, because the divider isolates while K4 switches). TMP275
25.5–26.3 °C. The first 20 s of each dwell are dropped: the 30 MΩ range is still settling by ~20 ppm
for the first few seconds. Data, figure and script:
[`calibration/2026-10-04_high-legs/`](../calibration/2026-10-04_high-legs/).

Each value is R_total = R_H + R_L + relay contacts + leads.

| Range | R_total | vs nominal R_H + 1 Ω | Part tolerance | N − I | Cycle-to-cycle |
|---|---|---|---|---|---|
| 1E-5 | **100,034 Ω** | +330 ppm | 0.1 % | 0.0 ppm | at the meter's 1 Ω (10 ppm) resolution: every reading identical |
| 1E-6 | **999,710 Ω** | −291 ppm | 0.1 % | +21 ppm | 6 ppm |
| 1E-7 | **10.0071–10.0081 MΩ** | +650 to +810 ppm | 1 % | +102 ppm | stepped (below) |

All three high legs are within their tolerances.

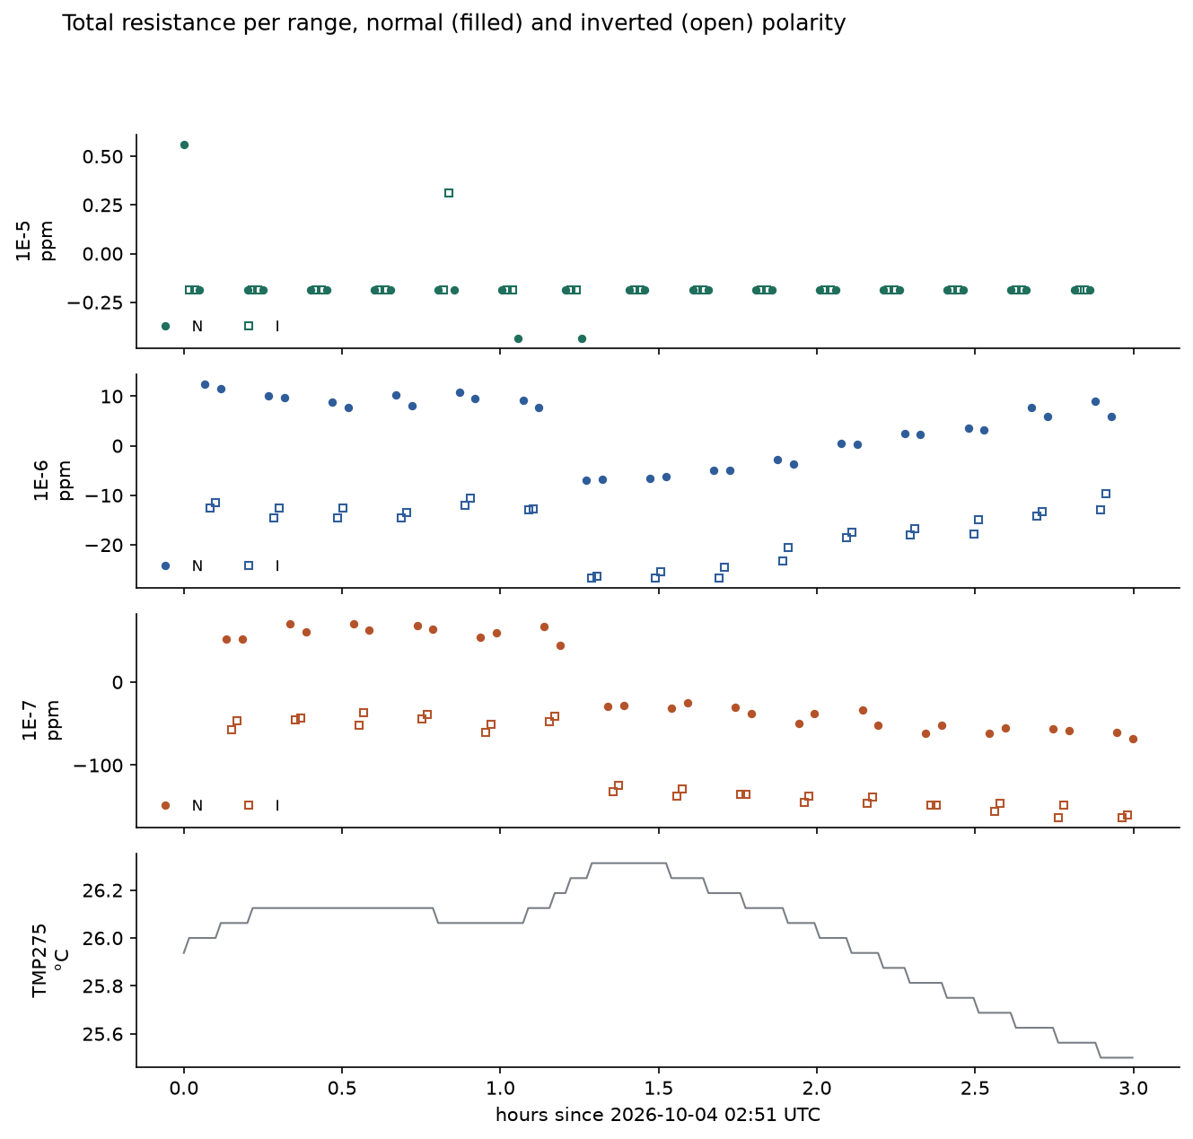
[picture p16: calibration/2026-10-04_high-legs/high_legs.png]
Total resistance per range over the session


**A step on the high-value ranges.** About 1.2 h in, 1E-6 fell 8 ppm on average (about 17 ppm at
first, recovering as the board cooled) and 1E-7 fell 102 ppm (10,008,133 → 10,007,116 Ω) and kept
sliding. 1E-5 did not move. It coincided with the operator leaving the bench; the cause is not
identified. The size of the shift grows steeply with resistance, about 1 Ω on 1 MΩ against about
1 kΩ on 10 MΩ. That is the signature of a parallel leakage of order 10¹¹ Ω, not of a tempco, which
would move each leg by a similar number of ppm.

**A polarity difference.** Normal and inverted polarity differ by +21 ppm on 1E-6 and +102 ppm on
1E-7, unchanged across the step, and not at all on 1E-5. A network of resistors cannot do this on
its own, however many leakage paths it has. It is reciprocal: measured between two terminals, its
resistance is the same whichever way round the meter is connected, and reversing K4 is equivalent to
swapping the meter leads on the divider. 1E-5, with N − I = 0.000 ppm, behaves exactly that way.

Two follow-up checks on 2026-10-05, with the meter on IN and the supply unplugged
([`followup_2026-10-05.json`](../calibration/2026-10-04_high-legs/followup_2026-10-05.json)):

* **Not a ground path.** One candidate was leakage from the precision nodes to the control ground,
  which reaches the meter's chassis through USB, the host and GPIB. The latching relays hold their
  state with no power, so 1E-7 was read in both polarities with the divider's USB unplugged. The
  difference remained: N − I = +79 ppm with USB unplugged, against +67 ppm with it connected.
* **A series EMF on the 10 MΩ leg.** DC volts at IN, with no ohms test current, flip with K4 by
  2 × 11.9 µV on 1E-7, against under 0.5 µV on 1E-5 and 1E-6. So there is an EMF of about 12 µV in the
  1E-7 chain, most likely at the terminations of the thick-film 10 MΩ resistor or in K3's contacts.
  An EMF E adds 2E/I_test to N − I in ohms mode. With the meter's 30 MΩ test current taken as
  0.1 µA, that accounts for about 240 Ω of the 674 Ω observed: roughly a third.

The rest is unexplained: about two thirds of the 1E-7 difference, and nearly all of the 1E-6 one,
whose chain shows no EMF. It needs something both leakage-like and non-reciprocal. A leak into the
unpowered coil-driver network, which contains diodes, is one candidate; it is not pursued here.

Averaging the two polarities cancels the EMF part, but **not** a leakage part: each polarity is
shunted differently, and the average is shunted by roughly their mean. R_total on 1E-6 and 1E-7 may
therefore read low by up to the polarity difference.

**Why the ratio is unaffected by most of this.**
* The EMF is in series with the 29 V source and is divided by the full ratio: 12 µV on 1E-7 is
  1.2 pV at OUT. In ratio mode it does not reverse with K4 either, so ABBA removes it.
* A leak to ground passes through neither R_H nor R_L.
* What would move a ratio is leakage *across* a high leg.

**What this means.** At 10 MΩ, leakage of 10¹¹–10¹² Ω is visible at the 10–100 ppm level. An
ohmmeter at IN cannot tell whether it is across the IN jacks and cables (which would not affect the
divider ratio) or across the 10 MΩ leg inside (which would move k₇ by the same amount). The ratio run
can: k₇ would show the same kind of steps. Until then, treat 1E-7 values at the 100 ppm level as
provisional.

### Null test (b), input shorted, 2026-10-04 – 05

**Conditions.** A copper link across NORMAL IN, the supply unplugged. HP 3478A on OUT, 30 mV range,
5½ digits, autozero on, 1 Hz. The full ratio-run schedule: per 13-minute cycle, ABBA on 1E-5, 1E-6
and 1E-7, then one ISOLATE dwell. 24 h, 110 blocks per range; 85,800 readings, none failed. TMP275
23.7–26.9 °C. The first 2 s of each dwell are dropped. Data, figure and script:
[`calibration/2026-10-04_null-short/`](../calibration/2026-10-04_null-short/).

| Range | Mean S | Block scatter | As ppm of the 29 V signal |
|---|---|---|---|
| 1E-5 | −1.1 ± 1.3 nV | 13.7 nV | −4 ± 5 ppm |
| 1E-6 | −1.2 ± 1.2 nV | 12.2 nV | −42 ± 40 ppm |
| 1E-7 | +1.9 ± 1.2 nV | 13.0 nV | +660 ± 430 ppm |
| All 330 blocks | **−0.1 ± 0.7 nV** | | |

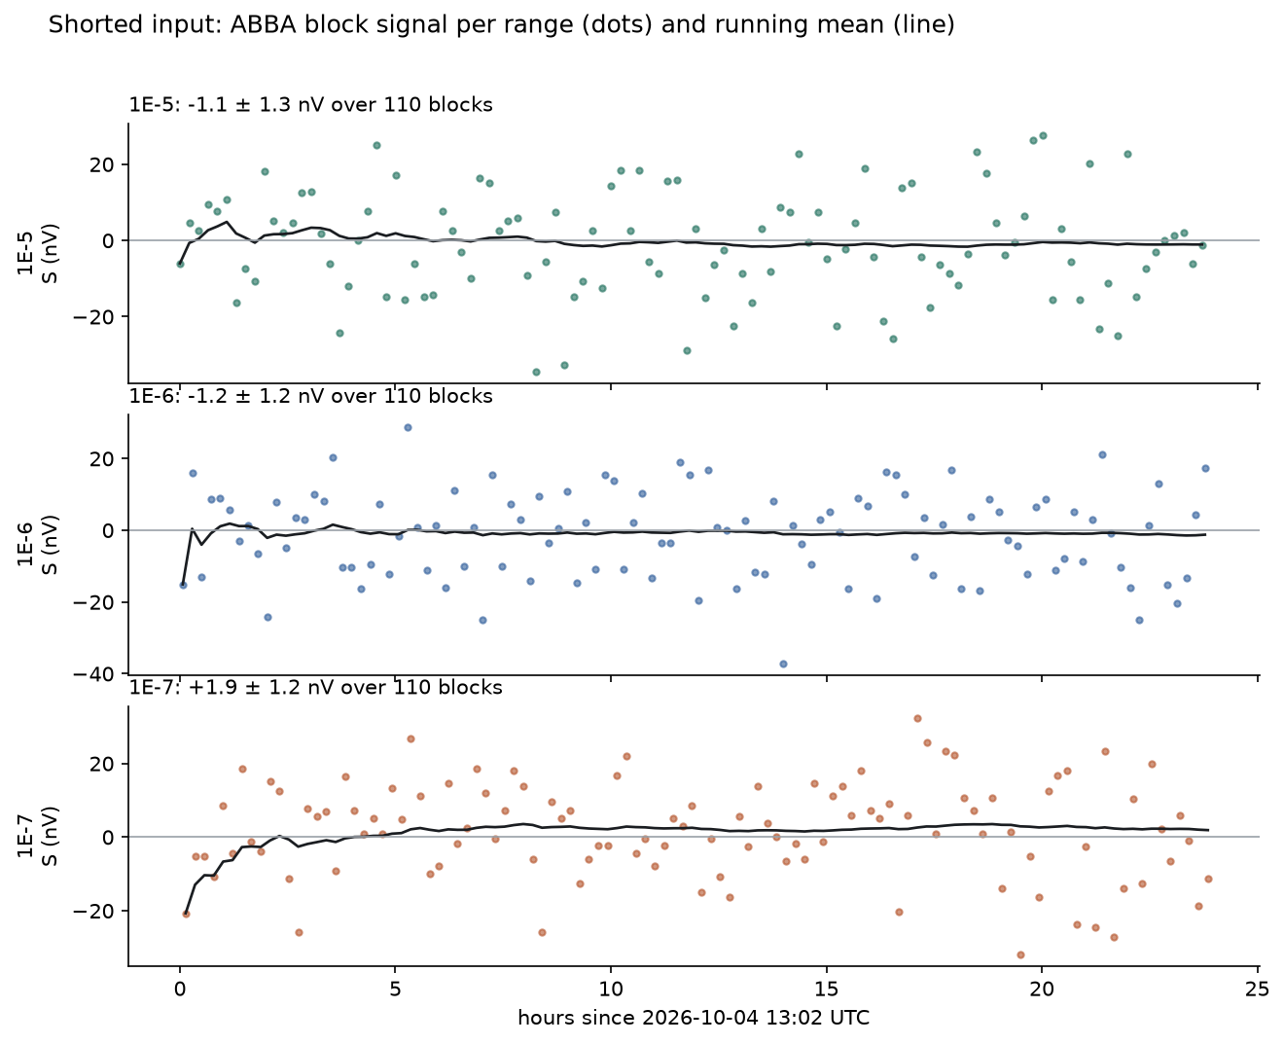
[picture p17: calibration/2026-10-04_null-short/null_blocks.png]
ABBA block signal per range with the input shorted


**No switching bias.** Every range is consistent with zero; the largest, 1E-7, is 1.5σ. The first and
second halves agree within their errors on each range. Over the whole run the meter's zero wandered
between −5.0 and −3.4 µV, and the injecting dwells sat 4–13 nV above the ISOLATE dwell. Both are
offsets that do not change with polarity, which ABBA removes from S, as the result shows.

**The method is twice as quiet as assumed.** A block scatters by about 13 nV, half the 26 nV the
uncertainty budget was planned on, and the block-to-block Allan deviation falls roughly as 1/√n out to
16 blocks. The statistical limits in [Uncertainty](#uncertainty) are updated accordingly.

What this bounds: a switching artefact in the signal path larger than about 2.5 nV (2σ) per range. It
does not test the supply as a source (variant c) or coupling from the coil drivers and controller
with the path open (variant a, which runs inside the ratio run).
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

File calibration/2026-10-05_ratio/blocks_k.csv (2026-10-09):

utc | range | k | tmp275_lagged_c
2026-10-05T16:13:11Z | 1E-5 | 9.979241243629369e-6 | 24.3452
2026-10-05T16:29:15Z | 1E-5 | 9.982124770233367e-6 | 24.3519
2026-10-05T16:45:18Z | 1E-5 | 9.981071670021929e-6 | 24.3614
2026-10-05T17:01:22Z | 1E-5 | 9.980866611217372e-6 | 24.3734
2026-10-05T17:17:26Z | 1E-5 | 9.981168187678426e-6 | 24.389
2026-10-05T17:33:30Z | 1E-5 | 9.980892112084806e-6 | 24.4099
2026-10-05T17:49:34Z | 1E-5 | 9.981287755058207e-6 | 24.439
2026-10-05T18:05:38Z | 1E-5 | 9.981549367138572e-6 | 24.4709
2026-10-05T18:21:42Z | 1E-5 | 9.981139761232118e-6 | 24.5007
2026-10-05T18:37:46Z | 1E-5 | 9.981203472828687e-6 | 24.5274
2026-10-05T18:53:50Z | 1E-5 | 9.98174407489122e-6 | 24.5572
2026-10-05T19:09:54Z | 1E-5 | 9.981693536287576e-6 | 24.5946
2026-10-05T19:25:58Z | 1E-5 | 9.98160069435387e-6 | 24.639
2026-10-05T19:42:02Z | 1E-5 | 9.98176220112223e-6 | 24.69
2026-10-05T19:58:06Z | 1E-5 | 9.98098675854726e-6 | 24.7433
2026-10-05T20:14:10Z | 1E-5 | 9.981859939130783e-6 | 24.7977
2026-10-05T20:30:13Z | 1E-5 | 9.981263332872365e-6 | 24.8572
2026-10-05T20:46:17Z | 1E-5 | 9.980962936844495e-6 | 24.9175
2026-10-05T21:02:21Z | 1E-5 | 9.981538535670649e-6 | 24.9783
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

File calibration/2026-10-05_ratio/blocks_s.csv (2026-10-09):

utc | cycle | range | pattern | s_nv
2026-10-05T16:13:11Z | 0 | 1E-5 | NIIN | 289453.02
2026-10-05T16:17:12Z | 0 | 1E-6 | NIIN | 28960.78
2026-10-05T16:21:13Z | 0 | 1E-7 | NIIN | 2883.62
2026-10-05T16:25:14Z | 0 | 1E-7 | niin | -0.86
2026-10-05T16:29:15Z | 1 | 1E-5 | NIIN | 289536.64
2026-10-05T16:33:16Z | 1 | 1E-6 | NIIN | 28967.24
2026-10-05T16:37:17Z | 1 | 1E-7 | NIIN | 2905.6
2026-10-05T16:41:18Z | 1 | 1E-7 | niin | 7.76
2026-10-05T16:45:18Z | 2 | 1E-5 | NIIN | 289506.03
2026-10-05T16:49:20Z | 2 | 1E-6 | NIIN | 28976.29
2026-10-05T16:53:21Z | 2 | 1E-7 | NIIN | 2887.07
2026-10-05T16:57:21Z | 2 | 1E-7 | niin | -1.29
2026-10-05T17:01:22Z | 3 | 1E-5 | NIIN | 289500.0
2026-10-05T17:05:23Z | 3 | 1E-6 | NIIN | 28965.52
2026-10-05T17:09:25Z | 3 | 1E-7 | NIIN | 2901.29
2026-10-05T17:13:25Z | 3 | 1E-7 | niin | -1.29
2026-10-05T17:17:26Z | 4 | 1E-5 | NIIN | 289508.62
2026-10-05T17:21:27Z | 4 | 1E-6 | NIIN | 28962.93
2026-10-05T17:25:29Z | 4 | 1E-7 | NIIN | 2867.67
2026-10-05T17:29:29Z | 4 | 1E-7 | niin | 6.9
2026-10-05T17:33:30Z | 5 | 1E-5 | NIIN | 289500.43
2026-10-05T17:37:31Z | 5 | 1E-6 | NIIN | 28957.33
2026-10-05T17:41:32Z | 5 | 1E-7 | NIIN | 2885.34
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

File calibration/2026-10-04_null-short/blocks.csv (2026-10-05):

utc | cycle | range | s_nv | tmp275_c
2026-10-04T13:02:23Z | 0 | 1E-5 | -6.03 | 23.6875
2026-10-04T13:06:24Z | 0 | 1E-6 | -15.09 | 23.8125
2026-10-04T13:10:26Z | 0 | 1E-7 | -20.69 | 23.875
2026-10-04T13:15:27Z | 1 | 1E-5 | 4.74 | 23.9375
2026-10-04T13:19:28Z | 1 | 1E-6 | 15.95 | 24.0
2026-10-04T13:23:29Z | 1 | 1E-7 | -5.17 | 24.0
2026-10-04T13:28:30Z | 2 | 1E-5 | 2.59 | 24.0
2026-10-04T13:32:31Z | 2 | 1E-6 | -12.93 | 23.9375
2026-10-04T13:36:32Z | 2 | 1E-7 | -5.17 | 23.9375
2026-10-04T13:41:34Z | 3 | 1E-5 | 9.48 | 23.9375
2026-10-04T13:45:35Z | 3 | 1E-6 | 8.62 | 23.9375
2026-10-04T13:49:36Z | 3 | 1E-7 | -10.78 | 23.9375
2026-10-04T13:54:37Z | 4 | 1E-5 | 7.76 | 23.9375
2026-10-04T13:58:38Z | 4 | 1E-6 | 9.05 | 23.875
2026-10-04T14:02:39Z | 4 | 1E-7 | 8.62 | 23.875
2026-10-04T14:07:40Z | 5 | 1E-5 | 10.78 | 23.875
2026-10-04T14:11:41Z | 5 | 1E-6 | 5.6 | 23.875
2026-10-04T14:15:43Z | 5 | 1E-7 | -4.31 | 23.875
2026-10-04T14:20:44Z | 6 | 1E-5 | -16.38 | 23.8125
2026-10-04T14:24:45Z | 6 | 1E-6 | -3.02 | 23.875
2026-10-04T14:28:46Z | 6 | 1E-7 | 18.53 | 23.875
2026-10-04T14:33:47Z | 7 | 1E-5 | -7.33 | 23.875
2026-10-04T14:37:48Z | 7 | 1E-6 | 1.29 | 23.875
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

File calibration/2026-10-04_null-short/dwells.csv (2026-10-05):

utc | cycle | range | pattern | mean_nv | sd_nv | samples | tmp275_c
2026-10-04T13:02:23Z | 0 | 1E-5 | N | -3424.14 | 104.8 | 58 | 23.6875
2026-10-04T13:03:24Z | 0 | 1E-5 | I | -3587.93 | 140.3 | 58 | 23.6875
2026-10-04T13:04:24Z | 0 | 1E-5 | I | -3760.34 | 109.1 | 58 | 23.75
2026-10-04T13:05:24Z | 0 | 1E-5 | N | -3948.28 | 138.0 | 58 | 23.75
2026-10-04T13:06:24Z | 0 | 1E-6 | N | -4063.79 | 134.7 | 58 | 23.8125
2026-10-04T13:07:25Z | 0 | 1E-6 | I | -4098.28 | 131.8 | 58 | 23.8125
2026-10-04T13:08:25Z | 0 | 1E-6 | I | -4127.59 | 134.8 | 58 | 23.8125
2026-10-04T13:09:25Z | 0 | 1E-6 | N | -4222.41 | 124.3 | 58 | 23.875
2026-10-04T13:10:26Z | 0 | 1E-7 | N | -4325.86 | 142.1 | 58 | 23.875
2026-10-04T13:11:26Z | 0 | 1E-7 | I | -4358.62 | 129.8 | 58 | 23.875
2026-10-04T13:12:26Z | 0 | 1E-7 | I | -4453.45 | 121.7 | 58 | 23.9375
2026-10-04T13:13:26Z | 0 | 1E-7 | N | -4568.97 | 107.9 | 58 | 23.9375
2026-10-04T13:14:26Z | 0 | 1E-7 | Z | -4568.97 | 118.8 | 58 | 23.9375
2026-10-04T13:15:27Z | 1 | 1E-5 | N | -4512.07 | 101.0 | 58 | 23.9375
2026-10-04T13:16:27Z | 1 | 1E-5 | I | -4543.1 | 123.0 | 58 | 23.9375
2026-10-04T13:17:27Z | 1 | 1E-5 | I | -4531.03 | 134.0 | 58 | 23.9375
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

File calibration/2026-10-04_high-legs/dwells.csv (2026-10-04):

utc | cycle | range | pattern | r_ohm | sd_ohm | samples | tmp275_c
2026-10-04T02:51:44Z | 0 | 1E-5 | N | 100034.075 | 0.267 | 40 | 25.9375
2026-10-04T02:52:44Z | 0 | 1E-5 | I | 100034.0 | 0.0 | 40 | 26.0
2026-10-04T02:53:44Z | 0 | 1E-5 | I | 100034.0 | 0.0 | 40 | 26.0
2026-10-04T02:54:45Z | 0 | 1E-5 | N | 100034.0 | 0.0 | 40 | 26.0
2026-10-04T02:55:45Z | 0 | 1E-6 | N | 999729.25 | 2.667 | 40 | 26.0
2026-10-04T02:56:46Z | 0 | 1E-6 | I | 999704.25 | 5.006 | 40 | 26.0
2026-10-04T02:57:46Z | 0 | 1E-6 | I | 999705.25 | 5.057 | 40 | 26.0
2026-10-04T02:58:46Z | 0 | 1E-6 | N | 999728.25 | 3.848 | 40 | 26.0625
2026-10-04T02:59:46Z | 0 | 1E-7 | N | 10008590.0 | 169.161 | 40 | 26.0625
2026-10-04T03:00:47Z | 0 | 1E-7 | I | 10007495.0 | 181.094 | 40 | 26.0625
2026-10-04T03:01:47Z | 0 | 1E-7 | I | 10007602.5 | 171.7 | 40 | 26.0625
2026-10-04T03:02:47Z | 0 | 1E-7 | N | 10008582.5 | 163.123 | 40 | 26.0625
2026-10-04T03:03:47Z | 1 | 1E-5 | N | 100034.0 | 0.0 | 40 | 26.0625
2026-10-04T03:04:48Z | 1 | 1E-5 | I | 100034.0 | 0.0 | 40 | 26.125
2026-10-04T03:05:48Z | 1 | 1E-5 | I | 100034.0 | 0.0 | 40 | 26.125
2026-10-04T03:06:48Z | 1 | 1E-5 | N | 100034.0 | 0.0 | 40 | 26.125
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

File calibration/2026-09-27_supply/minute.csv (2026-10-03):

utc | v_in_v | v_sd_v | samples | tmp275_c
2026-09-27T22:53:00Z | 29.0095407 | 0.0000533 | 54 | 24.35
2026-09-27T22:54:00Z | 29.009525 | 0.00006 | 60 | 24.375
2026-09-27T22:55:00Z | 29.0095 | 0.0000689 | 60 | 24.375
2026-09-27T22:56:00Z | 29.0094583 | 0.0000591 | 60 | 24.375
2026-09-27T22:57:00Z | 29.0094667 | 0.000051 | 60 | 24.4125
2026-09-27T22:58:00Z | 29.0094283 | 0.0000524 | 60 | 24.4375
2026-09-27T22:59:00Z | 29.0094117 | 0.0000666 | 60 | 24.4375
2026-09-27T23:00:00Z | 29.0093617 | 0.0000524 | 60 | 24.45
2026-09-27T23:01:00Z | 29.0093967 | 0.0000736 | 60 | 24.5
2026-09-27T23:02:00Z | 29.0093767 | 0.0000621 | 60 | 24.5
2026-09-27T23:03:00Z | 29.0093933 | 0.0000686 | 60 | 24.5
2026-09-27T23:04:00Z | 29.0093833 | 0.0000717 | 60 | 24.5
2026-09-27T23:05:00Z | 29.0093067 | 0.0000548 | 60 | 24.5375
2026-09-27T23:06:00Z | 29.009335 | 0.0000732 | 60 | 24.5625
2026-09-27T23:07:00Z | 29.00935 | 0.0000624 | 60 | 24.5625
2026-09-27T23:08:00Z | 29.0093317 | 0.0000701 | 60 | 24.5625
2026-09-27T23:09:00Z | 29.0093117 | 0.0000666 | 60 | 24.5625
2026-09-27T23:10:00Z | 29.0093533 | 0.0000536 | 60 | 24.5875
2026-09-27T23:11:00Z | 29.00931 | 0.0000477 | 60 | 24.625
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

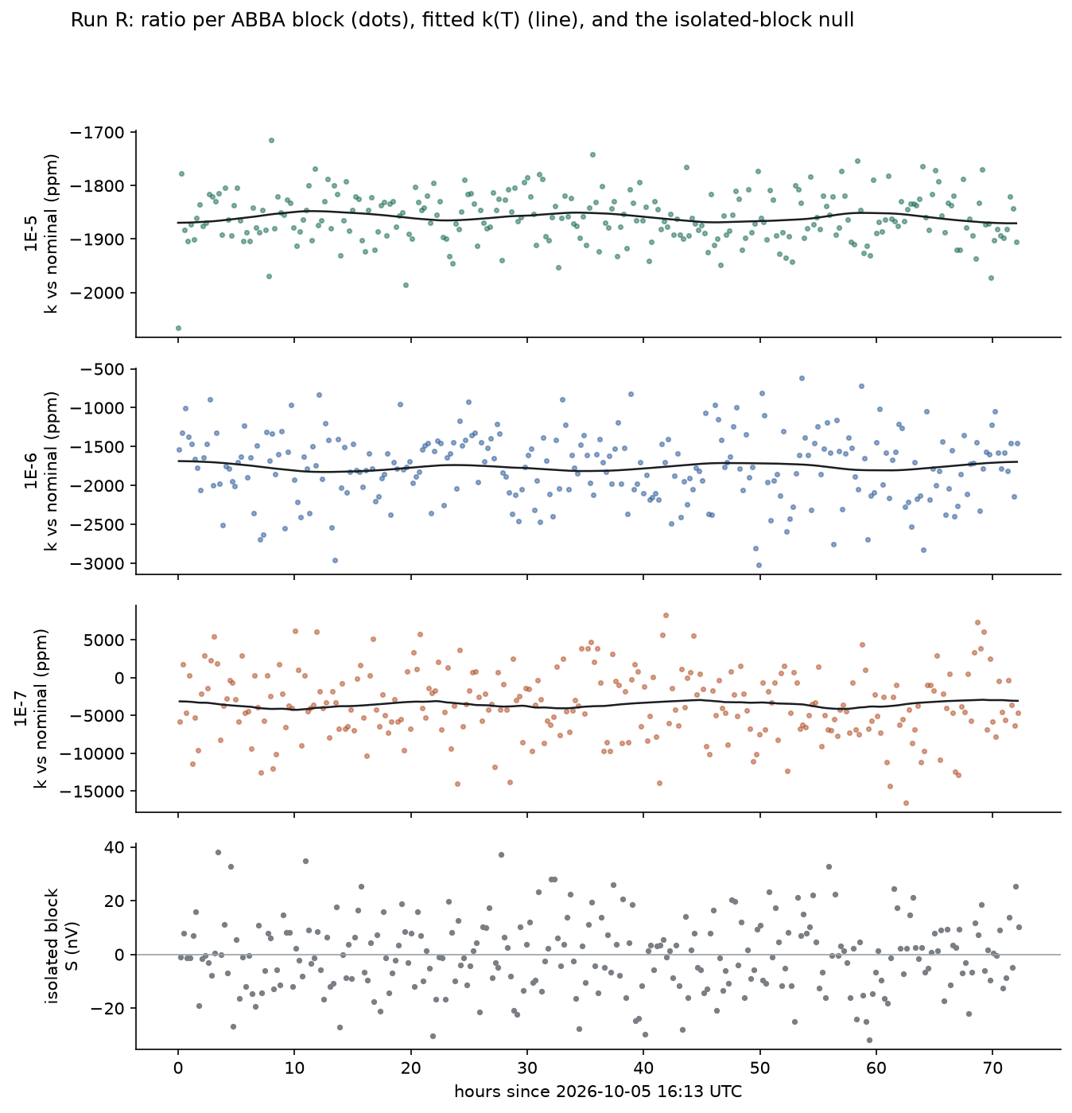
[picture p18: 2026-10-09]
calibration/2026-10-05_ratio/ratio_blocks.png

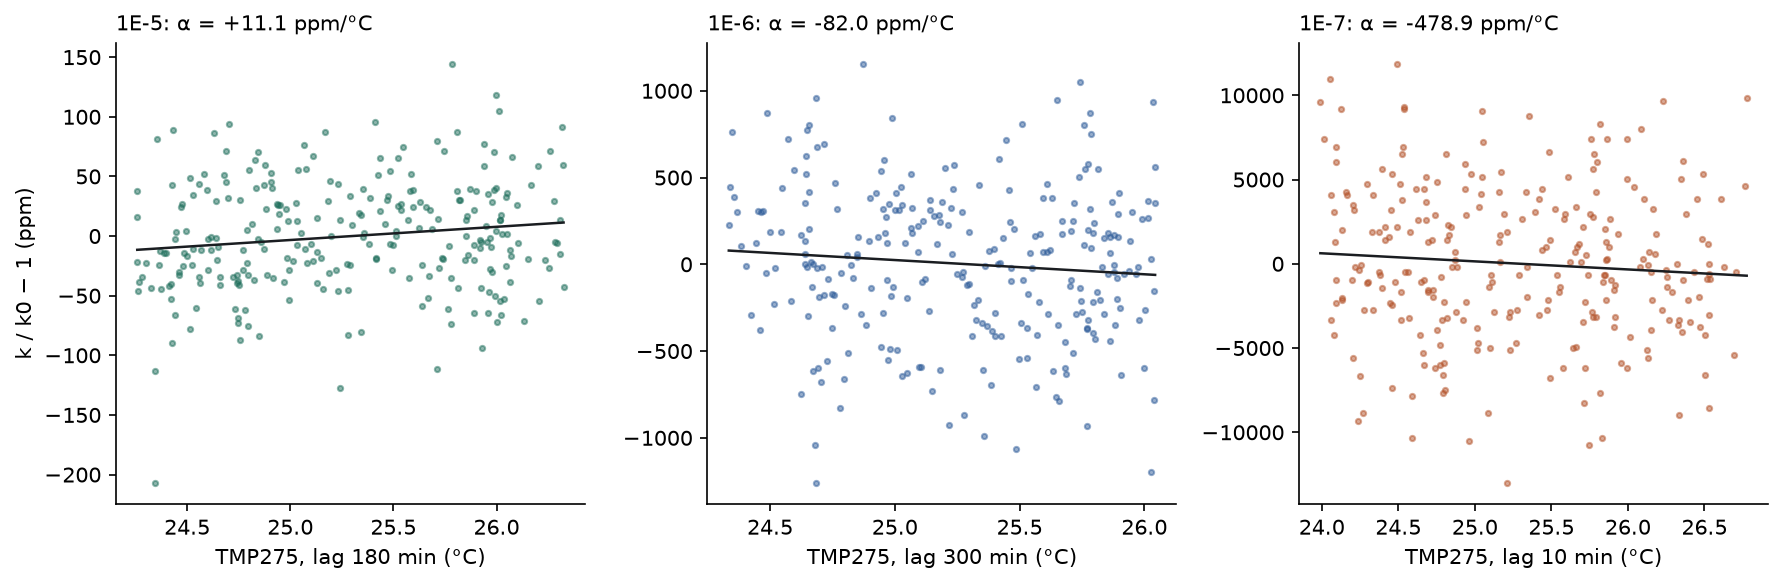
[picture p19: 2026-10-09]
calibration/2026-10-05_ratio/ratio_vs_temperature.png

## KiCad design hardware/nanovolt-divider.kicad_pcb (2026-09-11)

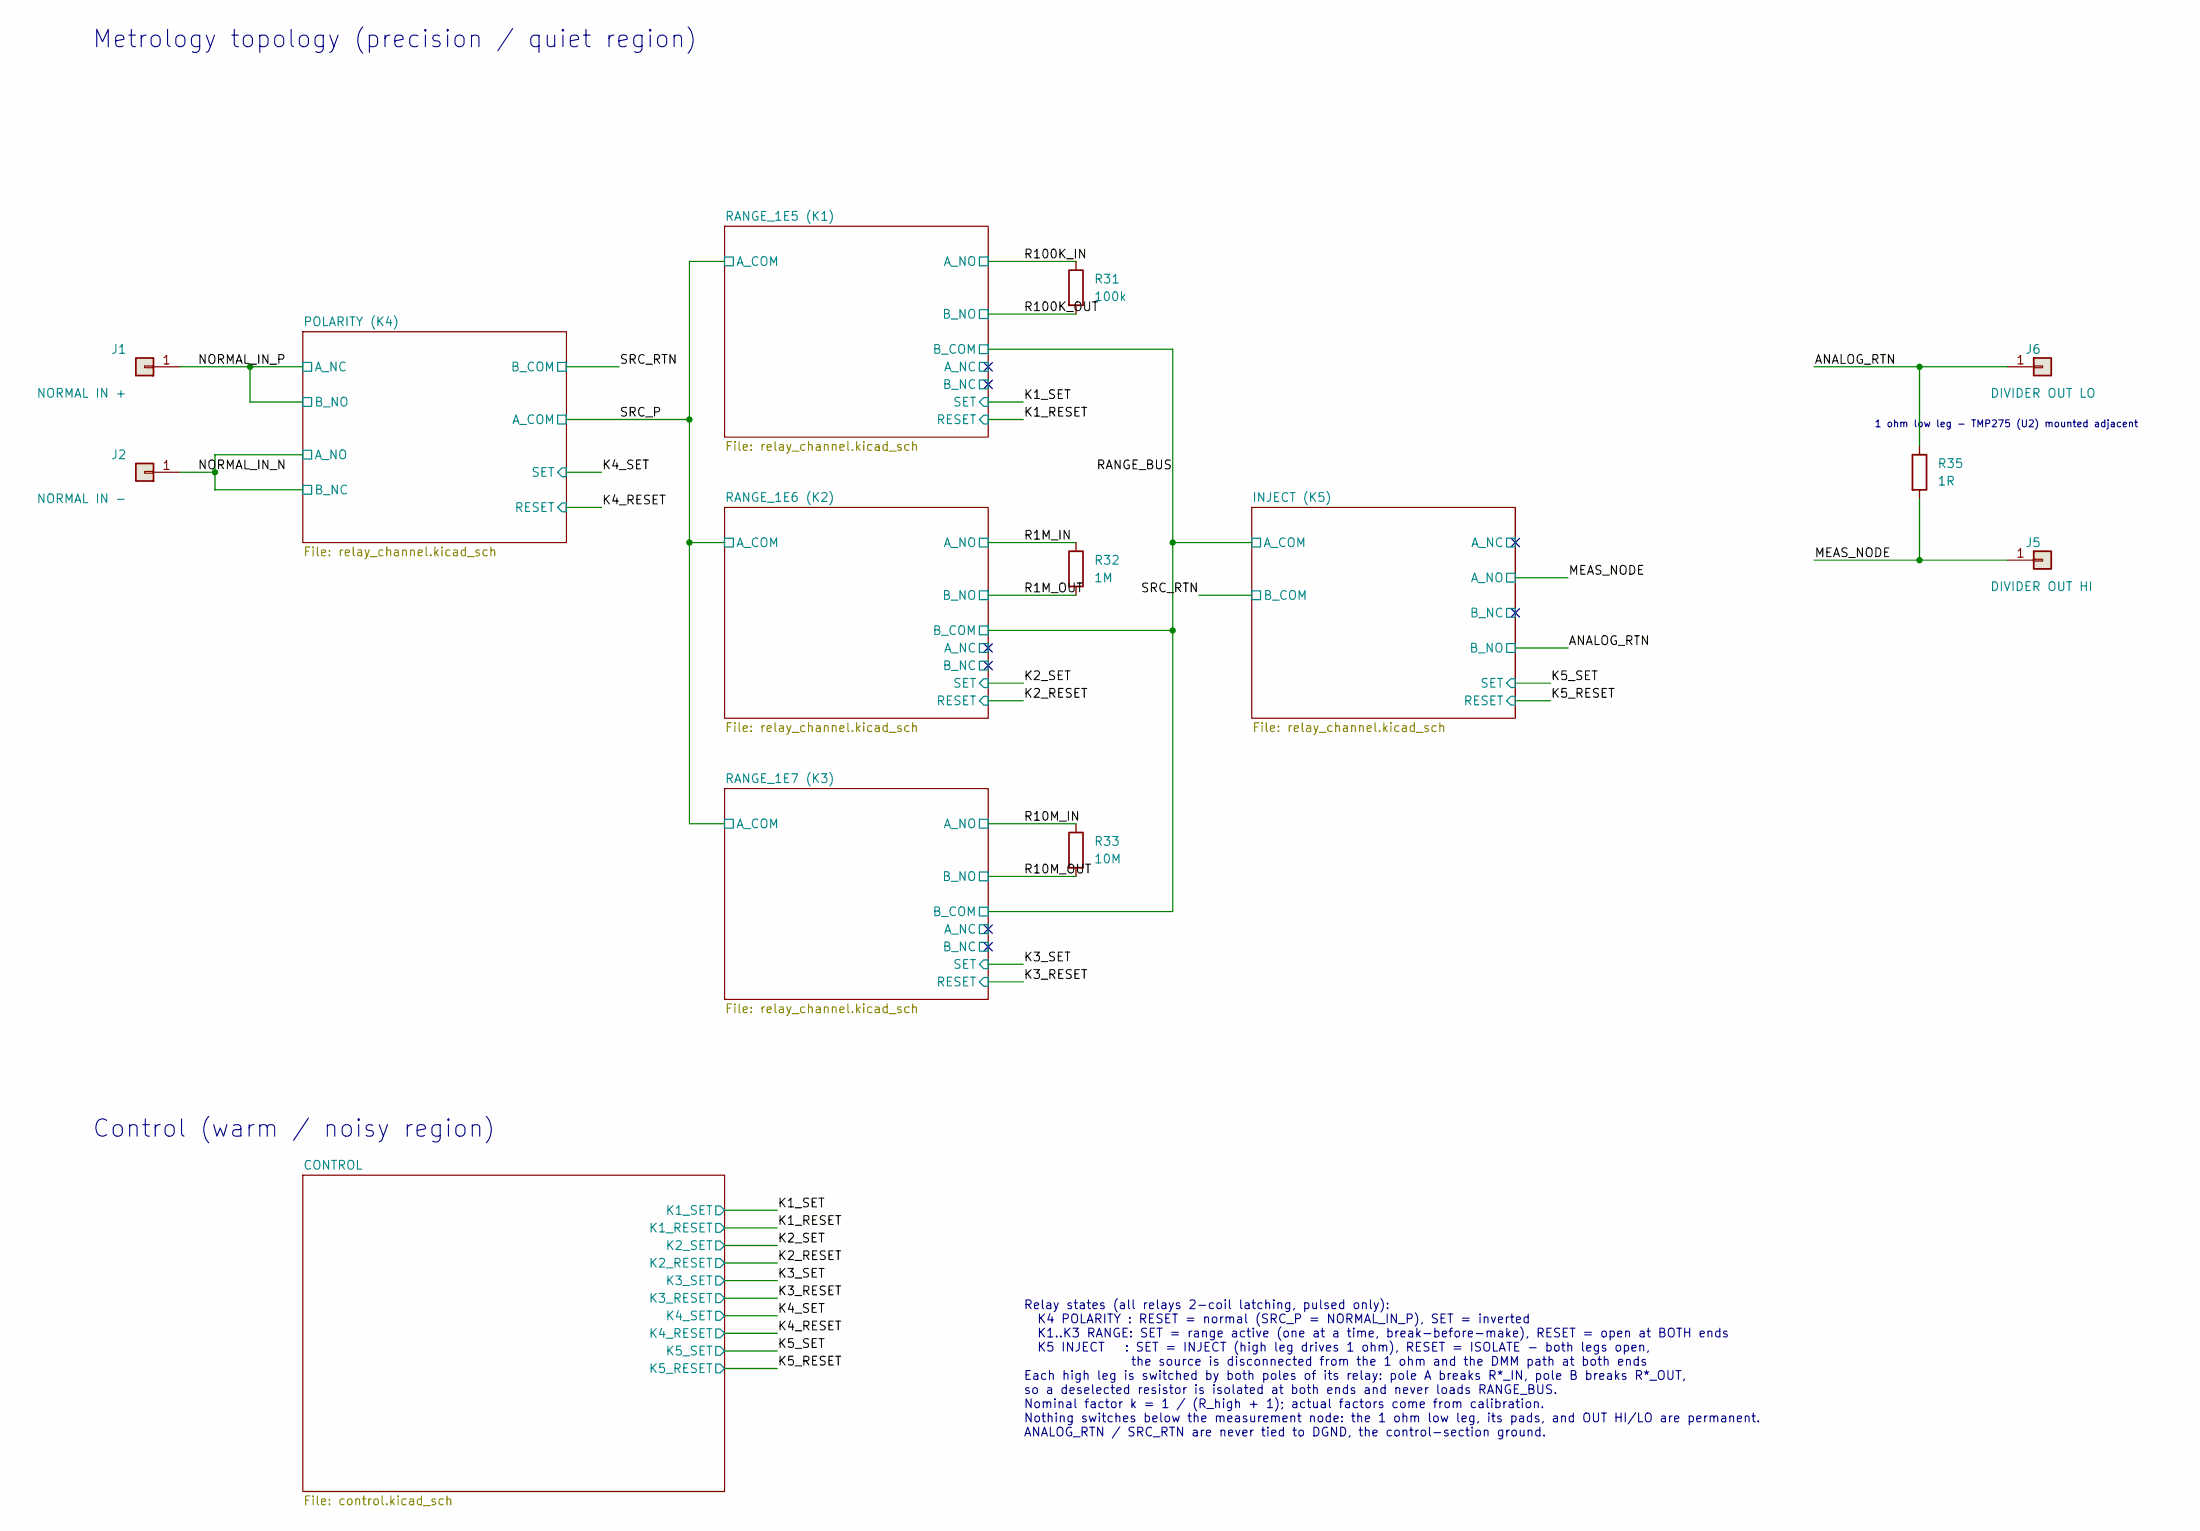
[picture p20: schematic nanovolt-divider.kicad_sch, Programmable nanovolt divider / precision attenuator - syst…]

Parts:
J1: NORMAL IN +; SolderWire-0.25sqmm_1x01_D0.65mm_OD1.7mm
J2: NORMAL IN -; SolderWire-0.25sqmm_1x01_D0.65mm_OD1.7mm
J5: DIVIDER OUT HI; SolderWire-0.25sqmm_1x01_D0.65mm_OD1.7mm
J6: DIVIDER OUT LO; SolderWire-0.25sqmm_1x01_D0.65mm_OD1.7mm
R31: 100k; R_Axial_Ohmite_MOX700_L7.0mm_D2.7mm_P10.16mm_Horizontal; MPN MOX70031003BZE
R32: 1M; R_Axial_Ohmite_MOX700_L7.0mm_D2.7mm_P10.16mm_Horizontal; MPN MOX70031004BYE
R33: 10M; R_Radial_Ohmite_SlimMox_SM102_L14.7mm_W2.5mm_P10.16mm; MPN SM102031005FE
R35: 1R; R_Axial_Vishay_RS02C_L15.1mm_D5.6mm_P20.32mm_Horizontal; MPN RS02C1R000FE70

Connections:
/ANALOG_RTN: J6.1, R35.1; also elsewhere on the board
/MEAS_NODE: J5.1, R35.2; also elsewhere on the board
/NORMAL_IN_N: J2.1; also elsewhere on the board
/NORMAL_IN_P: J1.1; also elsewhere on the board
/R1M_IN: R32.1; also elsewhere on the board
/R1M_OUT: R32.2; also elsewhere on the board
/R10M_IN: R33.1; also elsewhere on the board
/R10M_OUT: R33.2; also elsewhere on the board
/R100K_IN: R31.1; also elsewhere on the board
/R100K_OUT: R31.2; also elsewhere on the board

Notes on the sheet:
Metrology topology (precision / quiet region)
Control (warm / noisy region)
Relay states (all relays 2-coil latching, pulsed only): K4 POLARITY : RESET = normal (SRC_P = NORMAL_IN_P), SET = inverted K1..K3 RANGE: SET = range active (one at a time, break-before-make), RESET = open at BOTH ends K5 INJECT : SET = INJECT (high leg drives 1 ohm), RESET = ISOLATE - both legs ope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
1 ohm low leg - TMP275 (U2) mounted adjacent

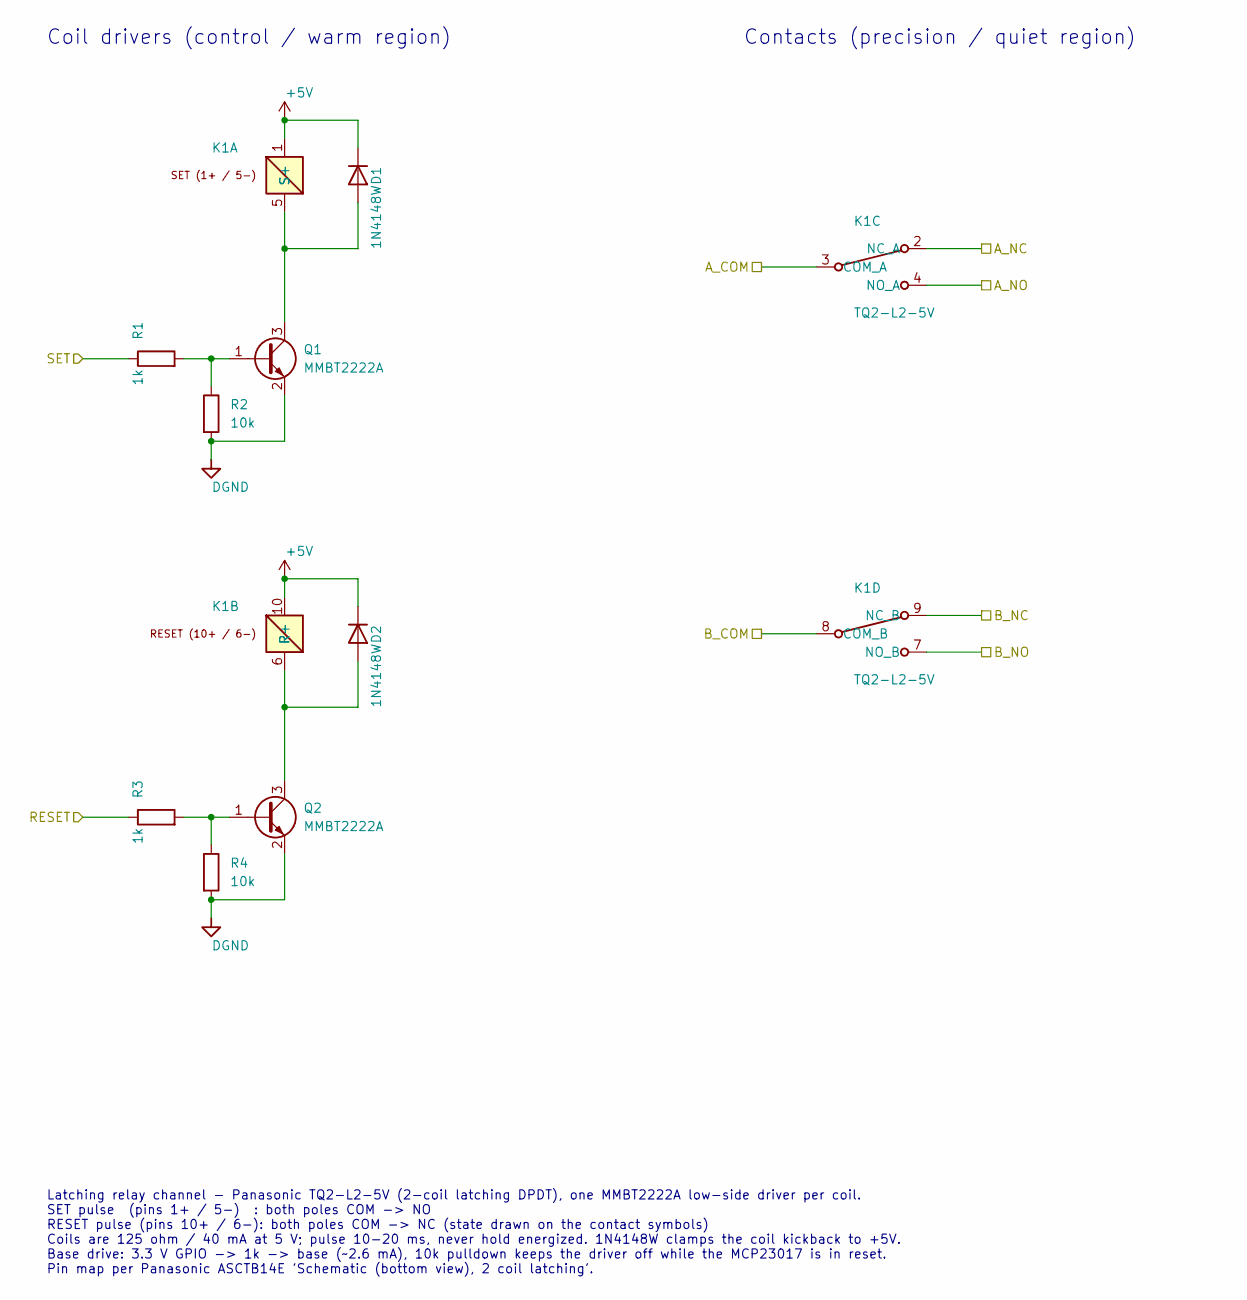
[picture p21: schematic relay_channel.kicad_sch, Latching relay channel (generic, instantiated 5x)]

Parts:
D1, D2: 1N4148W; D_SOD-123
K1: TQ2-L2-5V; Relay_DPDT_Panasonic_TQ2_THT
Q1, Q2: MMBT2222A; SOT-23
R1, R3: 1k; R_1206_3216Metric
R2, R4: 10k; R_1206_3216Metric

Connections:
+5V: D1.1 (K), D2.1 (K), K1.1 (S+), K1.10 (R+); also elsewhere on the board
/K1_RESET: R3.1; also elsewhere on the board
/K1_SET: R1.1; also elsewhere on the board
/R100K_IN: K1.4 (NO_A); also elsewhere on the board
/R100K_OUT: K1.7 (NO_B); also elsewhere on the board
/RANGE_1E5 (K1)/A_NC: K1.2 (NC_A)
/RANGE_1E5 (K1)/B_NC: K1.9 (NC_B)
/RANGE_BUS: K1.8 (COM_B); also elsewhere on the board
/SRC_P: K1.3 (COM_A); also elsewhere on the board
DGND: Q1.2 (E), Q2.2 (E), R2.2, R4.2; also elsewhere on the board
unnamed: D1.2 (A), K1.5 (S-), Q1.3 (C)
unnamed: D2.2 (A), K1.6 (R-), Q2.3 (C)
unnamed: Q1.1 (B), R1.2, R2.1
unnamed: Q2.1 (B), R3.2, R4.1

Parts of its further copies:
D3, D4, D5, D6, D7, D8, D9, D10: 1N4148W; D_SOD-123
K2, K3, K4, K5: TQ2-L2-5V; Relay_DPDT_Panasonic_TQ2_THT
Q3, Q4, Q5, Q6, Q7, Q8, Q9, Q10: MMBT2222A; SOT-23
R5, R7, R9, R11, R13, R15, R17, R19: 1k; R_1206_3216Metric
R6, R8, R10, R12, R14, R16, R18, R20: 10k; R_1206_3216Metric

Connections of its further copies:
+5V: D3.1 (K), D4.1 (K), D5.1 (K), D6.1 (K), D7.1 (K), D8.1 (K), D9.1 (K), D10.1 (K), K2.1 (S+), K2.10 (R+), K3.1 (S+), K3.10 (R+), K4.1 (S+), K4.10 (R+), K5.1 (S+), K5.10 (R+); also elsewhere on the board
/ANALOG_RTN: K5.7 (NO_B); also elsewhere on the board
/INJECT (K5)/A_NC: K5.2 (NC_A)
/INJECT (K5)/B_NC: K5.9 (NC_B)
/K2_RESET: R7.1; also elsewhere on the board
/K2_SET: R5.1; also elsewhere on the board
/K3_RESET: R11.1; also elsewhere on the board
/K3_SET: R9.1; also elsewhere on the board
/K4_RESET: R15.1; also elsewhere on the board
/K4_SET: R13.1; also elsewhere on the board
/K5_RESET: R19.1; also elsewhere on the board
/K5_SET: R17.1; also elsewhere on the board
/MEAS_NODE: K5.4 (NO_A); also elsewhere on the board
/NORMAL_IN_N: K4.4 (NO_A), K4.9 (NC_B); also elsewhere on the board
/NORMAL_IN_P: K4.2 (NC_A), K4.7 (NO_B); also elsewhere on the board
/R1M_IN: K2.4 (NO_A); also elsewhere on the board
/R1M_OUT: K2.7 (NO_B); also elsewhere on the board
/R10M_IN: K3.4 (NO_A); also elsewhere on the board
/R10M_OUT: K3.7 (NO_B); also elsewhere on the board
/RANGE_1E6 (K2)/A_NC: K2.2 (NC_A)
/RANGE_1E6 (K2)/B_NC: K2.9 (NC_B)
/RANGE_1E7 (K3)/A_NC: K3.2 (NC_A)
/RANGE_1E7 (K3)/B_NC: K3.9 (NC_B)
/RANGE_BUS: K2.8 (COM_B), K3.8 (COM_B), K5.3 (COM_A); also elsewhere on the board
/SRC_P: K2.3 (COM_A), K3.3 (COM_A), K4.3 (COM_A); also elsewhere on the board
/SRC_RTN: K4.8 (COM_B), K5.8 (COM_B)
DGND: Q3.2 (E), Q4.2 (E), Q5.2 (E), Q6.2 (E), Q7.2 (E), Q8.2 (E), Q9.2 (E), Q10.2 (E), R6.2, R8.2, R10.2, R12.2, R14.2, R16.2, R18.2, R20.2; also elsewhere on the board
unnamed: D3.2 (A), K2.5 (S-), Q3.3 (C)
unnamed: D4.2 (A), K2.6 (R-), Q4.3 (C)
unnamed: D5.2 (A), K3.5 (S-), Q5.3 (C)
unnamed: D6.2 (A), K3.6 (R-), Q6.3 (C)
unnamed: D7.2 (A), K4.5 (S-), Q7.3 (C)
unnamed: D8.2 (A), K4.6 (R-), Q8.3 (C)
unnamed: D9.2 (A), K5.5 (S-), Q9.3 (C)
unnamed: D10.2 (A), K5.6 (R-), Q10.3 (C)
unnamed: Q3.1 (B), R5.2, R6.1
unnamed: Q4.1 (B), R7.2, R8.1
unnamed: Q5.1 (B), R9.2, R10.1
unnamed: Q6.1 (B), R11.2, R12.1
unnamed: Q7.1 (B), R13.2, R14.1
unnamed: Q8.1 (B), R15.2, R16.1
unnamed: Q9.1 (B), R17.2, R18.1
unnamed: Q10.1 (B), R19.2, R20.1

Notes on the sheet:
Latching relay channel - Panasonic TQ2-L2-5V (2-coil latching DPDT), one MMBT2222A low-side driver per coil. SET pulse (pins 1+ / 5-) : both poles COM -> NO RESET pulse (pins 10+ / 6-): both poles COM -> NC (state drawn on the contact symbols) Coils are 125 ohm / 40 mA at 5 V; pulse 10-20 ms, never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
Coil drivers (control / warm region)
Contacts (precision / quiet region)

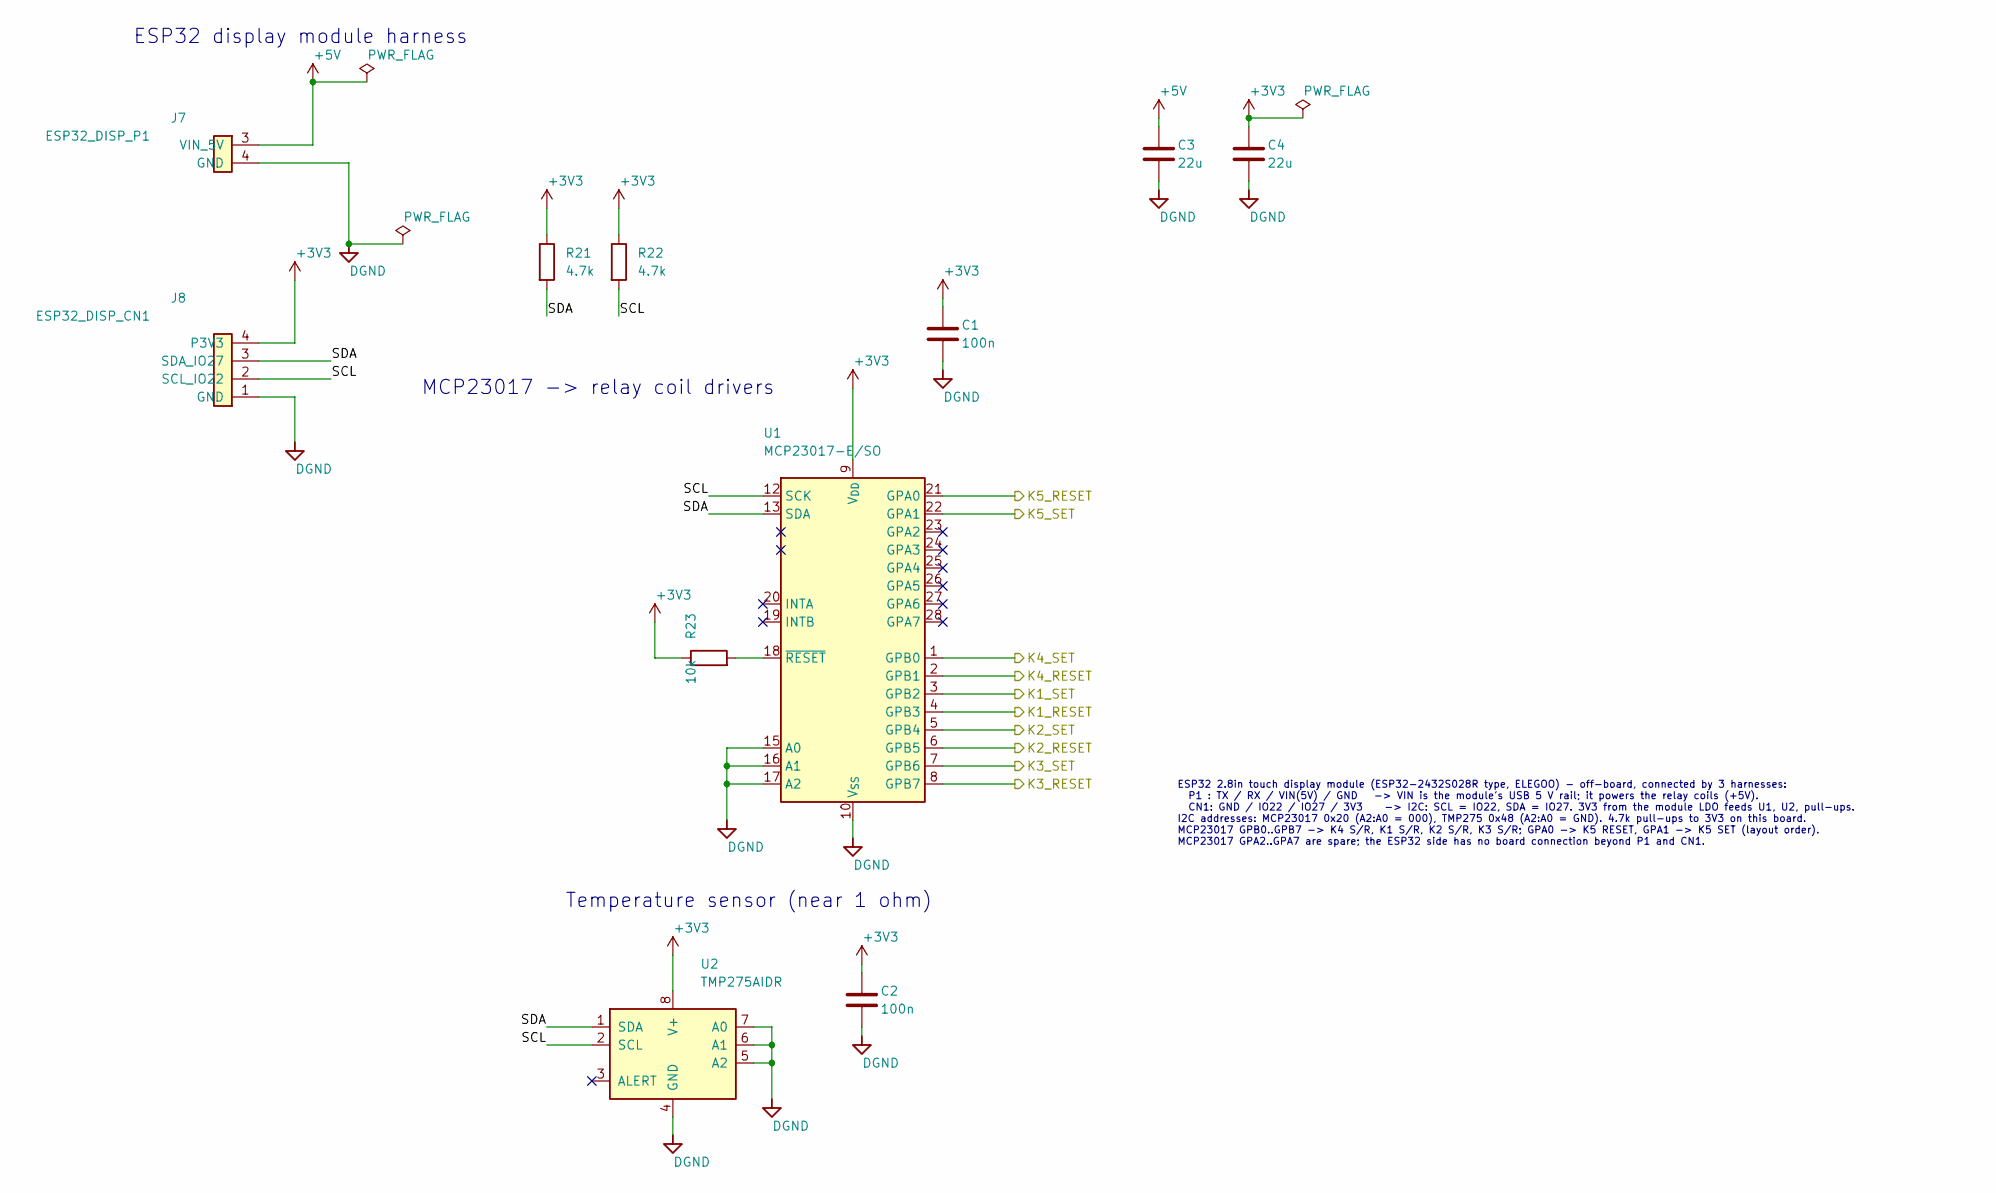
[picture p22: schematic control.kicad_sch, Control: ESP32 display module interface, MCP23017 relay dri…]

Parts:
C1, C2: 100n; C_1206_3216Metric; MPN SH31B104K160CT
C3, C4: 22u; C_1206_3216Metric; MPN EMK316BB7226ML-T
J7: ESP32_DISP_P1; J_ESP32_P1_WirePads
J8: ESP32_DISP_CN1; J_ESP32_CN1_WirePads
R21, R22: 4.7k; R_1206_3216Metric
R23: 10k; R_1206_3216Metric
U1: MCP23017-E/SO; SOIC-28W_7.5x17.9mm_P1.27mm; MPN MCP23017-E/SO
U2: TMP275AIDR; SOIC-8_3.9x4.9mm_P1.27mm; MPN TMP275AIDR

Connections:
+3V3: C1.1, C2.1, C4.1, J8.4 (P3V3), R21.1, R22.1, R23.1, U1.9 (V_{DD}), U2.8 (V+)
+5V: C3.1, J7.3 (VIN_5V); also elsewhere on the board
/CONTROL/SCL: J8.2 (SCL_IO22), R22.2, U1.12 (SCK), U2.2 (SCL)
/CONTROL/SDA: J8.3 (SDA_IO27), R21.2, U1.13 (SDA), U2.1 (SDA)
/K1_RESET: U1.4 (GPB3); also elsewhere on the board
/K1_SET: U1.3 (GPB2); also elsewhere on the board
/K2_RESET: U1.6 (GPB5); also elsewhere on the board
/K2_SET: U1.5 (GPB4); also elsewhere on the board
/K3_RESET: U1.8 (GPB7); also elsewhere on the board
/K3_SET: U1.7 (GPB6); also elsewhere on the board
/K4_RESET: U1.2 (GPB1); also elsewhere on the board
/K4_SET: U1.1 (GPB0); also elsewhere on the board
/K5_RESET: U1.21 (GPA0); also elsewhere on the board
/K5_SET: U1.22 (GPA1); also elsewhere on the board
DGND: C1.2, C2.2, C3.2, C4.2, J7.4 (GND), J8.1 (GND), U1.10 (V_{SS}), U1.15 (A0), U1.16 (A1), U1.17 (A2), U2.4 (GND), U2.5 (A2), U2.6 (A1), U2.7 (A0); also elsewhere on the board
unnamed: R23.2, U1.18 (~RESET)

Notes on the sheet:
ESP32 2.8in touch display module (ESP32-2432S028R type, ELEGOO) - off-board, connected by 3 harnesses: P1 : TX / RX / VIN(5V) / GND -> VIN is the module's USB 5 V rail; it powers the relay coils (+5V). CN1: GND / IO22 / IO27 / 3V3 -> I2C: SCL = IO22, SDA = IO27. 3V3 from the module LDO feeds U1, U2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
ESP32 display module harness
MCP23017 -> relay coil drivers
Temperature sensor (near 1 ohm)

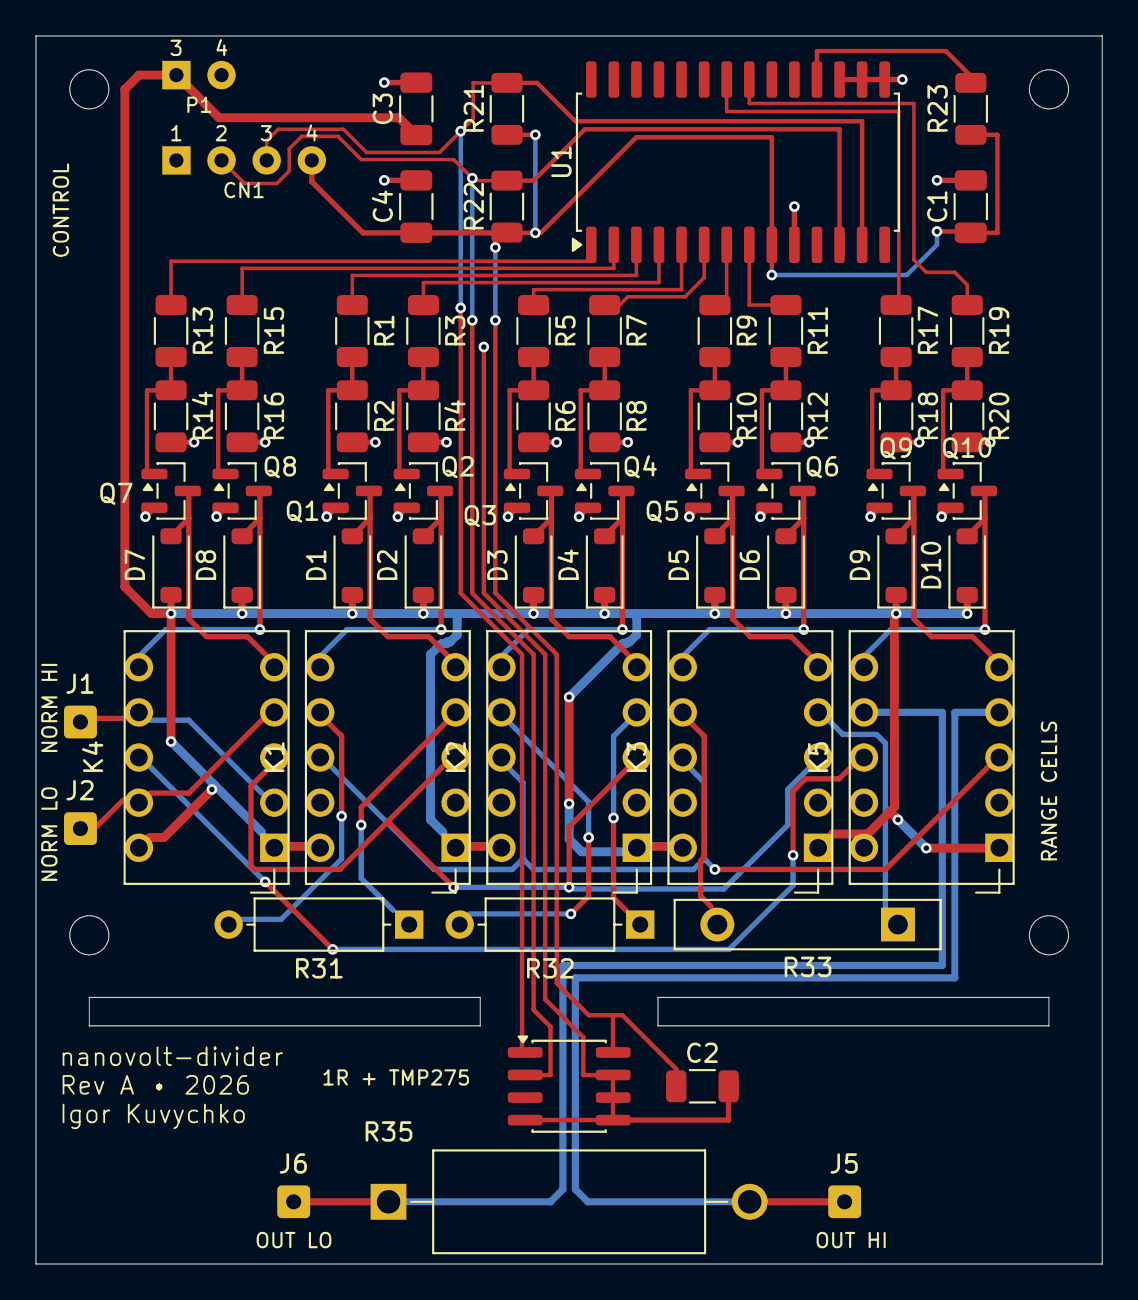
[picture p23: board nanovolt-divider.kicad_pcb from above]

Board: 2 copper layers, 60.0 x 69.1 mm, 68 parts (0 on the bottom side), 49 nets.

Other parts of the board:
H1, H2, H3, H4: M2; MountingHole_2.2mm_M2

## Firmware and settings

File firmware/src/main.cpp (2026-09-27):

// Nanovolt divider Rev A firmware.
//
// Boot order matters: the MCP23017 keeps its output latches across an ESP32 reboot, so its
// latches are cleared before anything else (including the display) is brought up.
#include <Arduino.h>

#include "bus.h"
#include "calibration.h"
#include "coils.h"
#include "instrument.h"
#include "mcp23017.h"
#include "pins.h"
#include "scpi.h"
#include "sdstore.h"
#include "settings.h"
#include "tmp275.h"
#include "ui.h"

namespace {

class NullPrint : public Print {
 public:
  size_t write(uint8_t) override { return 1; }
};

char g_line[256];
size_t g_line_len = 0;
bool g_line_overflow = false;

void pollSerial() {
  while (Serial.available()) {
    const char ch = Serial.read();
    if (ch == '\n' || ch == '\r') {
      if (g_line_overflow) {
        scpi::pushError(-112, "Program mnemonic too long;line over 255 chars");
      } else if (g_line_len) {
        g_line[g_line_len] = '\0';
        scpi::execute(g_line, Serial);
      }
      g_line_len = 0;
      g_line_overflow = false;
    } else if (g_line_len < sizeof(g_line) - 1) {
      g_line[g_line_len++] = ch;
    } else {
      g_line_overflow = true;
    }
  }
}

void logChange(const char *event) { sdstore::logEvent(event); }

}  // namespace

void setup() {
  bus::begin();
  mcp::init();  // clears any coil left energised by a reboot mid-pulse

  Serial.begin(115200);
  // The RGB LED is inside the enclosure, where it only costs power: driven off (it is active
  // low) and never touched again.
  for (int p : {pins::LED_R, pins::LED_G, pins::LED_B}) {
    pinMode(p, OUTPUT);
    digitalWrite(p, HIGH);
  }

  settings::begin();
  coils::setPulseMs(settings::get().pulseMs);
  coils::setGapMs(settings::get().gapMs);
  cal::begin();
  tmp275::init();

  Serial.printf("# nanovolt-divider fw %s%s\n", NVD_FW_VERSION,
#ifdef NVD_SIM_BOARD
                " (SIMULATED BOARD)"
#else
                ""
#endif
  );
  Serial.printf("# boot %lu\n", (unsigned long)settings::bootCount());
  Serial.printf("# MCP23017 %s, TMP275 %s, boot safe state %s\n",
                mcp::present() ? "found" : "NOT FOUND", tmp275::present() ? "found" : "NOT FOUND",
                settings::get().bootSafe ? "ON" : "OFF (relays not pulsed)");

  instrument::begin(settings::get().bootSafe);
  instrument::setChangeHook(logChange);

  NullPrint np;
  sdstore::info(np);  // sets the SD status indicator

  ui::begin();
  Serial.println("# ready");
}

void loop() {
  pollSerial();
  instrument::poll();
  tmp275::poll();
  sdstore::poll();
  ui::loop();
}

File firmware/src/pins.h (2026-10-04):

// Pin map for the ESP32-2432S028R ("Cheap Yellow Display") as wired to the Rev A board.
// Board-side wiring: see the "Display harness" table in docs/hardware.md.
#pragma once
#include <stdint.h>

namespace pins {

// I2C to the Rev A board (J8). The module has no IO22, so the bus lives on the SPI connector:
// SDA = IO27, SCL = IO18. Pull-ups are R21/R22 (4.7k to 3V3) on the board.
constexpr int I2C_SDA = 27;
constexpr int I2C_SCL = 18;

// microSD slot (VSPI pins). SCK is IO18 - shared with I2C SCL; see bus.h for arbitration.
constexpr int SD_SCK = 18;
constexpr int SD_MISO = 19;
constexpr int SD_MOSI = 23;
constexpr int SD_CS = 5;

// TFT (HSPI).
constexpr int TFT_SCK = 14;
constexpr int TFT_MOSI = 13;
constexpr int TFT_MISO = 12;
constexpr int TFT_CS = 15;
constexpr int TFT_DC = 2;
constexpr int TFT_BL = 21;

// XPT2046 resistive touch - its own pins, read by bit-bang (touch.cpp) so it takes no SPI host.
constexpr int TOUCH_CLK = 25;
constexpr int TOUCH_MOSI = 32;
constexpr int TOUCH_MISO = 39;  // input-only pin
constexpr int TOUCH_CS = 33;
constexpr int TOUCH_IRQ = 36;   // input-only pin, low while touched

// RGB LED, active low. Held off permanently: it is inside the enclosure (main.cpp).
constexpr int LED_R = 4;
constexpr int LED_G = 16;
constexpr int LED_B = 17;

}  // namespace pins

// I2C addresses on the Rev A board.
constexpr uint8_t MCP23017_ADDR = 0x20;  // A2:A0 = 000
constexpr uint8_t TMP275_ADDR = 0x48;    // A2:A0 = DGND

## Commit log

2026-09-07 Initial commit: Rev0 spec and hierarchical KiCad schematics
    - docs/nanovolt_divider_rev0.md: architecture and BOM specification
    - hardware/: KiCad 10 project with root (metrology topology), control
    (ESP32 display module harness, MCP23017, TMP117), and a generic
    relay_channel sheet instantiated 5x (K1..K5, Panasonic TQ2-L2-5V)
    - hardware/lib/: project symbol library (TQ2-L2-5V, SW_3PDT) and
    footprint library (TQ2 THT), authored from manufacturer drawings
    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
    [control.kicad_sch, nanovolt-divider.kicad_sch, relay_channel.kicad_sch]
2026-09-07 Capacitors: 100 nF and 22 uF both confirmed 1206 X7R
    Claude-Session: https://claude.ai/code/session_012iVAGTG9sDDBFakz9fB6fg
    [control.kicad_sch]
2026-09-07 PCB: placed, unrouted Rev0 board with HV rules and project footprints
    - hardware/nanovolt-divider.kicad_pcb: 100 x 62 mm, 2 layers, control /
    precision sections separated by a slot, relays in a row across from
    their drivers, HV parts spaced, 1 ohm corner with L slot and TMP117,
    GND pour limited to the control section, precision no-pour keepout,
    4x M3 holes. Nets assigned from the schematic netlist; no tracks yet.
    - hardware/nanovolt-divider.kicad_dru: HV netclass clearance 3 mm,
    creepage 4 mm, edge clearance; DSBGA clearance; slot-bridge track width
    - Project footprints authored from datasheets / measured parts: Ohmite
    MOX-700, Slim-Mox SM102, Vishay RS-2C, 3x3 switch wiring pads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
    [nanovolt-divider.kicad_pcb, nanovolt-divider.kicad_sch]
2026-09-07 PCB: portrait top-down layout, notch-isolated 1 ohm strip
    - 60 x 103 mm: harness connectors, MCP23017 (horizontal, flanked by
    caps and pull-ups), coil drivers above their relays, relay row, then
    the quiet section (high legs, 3PDT pads, HV, 1 ohm strip)
    - 1 ohm strip isolated by two edge notches with a 10 mm centre bridge
    for MEAS / return / TMP117 lines; driver-to-relay slot removed
    - DRC: only unrouted ratsnest and silkscreen warnings remain
    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
    [nanovolt-divider.kicad_pcb]
2026-09-07 PCB: 1 ohm isolation as two internal slots with 3 mm edge bridges
    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
    [nanovolt-divider.kicad_pcb]
2026-09-07 Rev0: named analog nets, both relay poles, HV netclass, smaller board
    Restore the HV netclass (the real bug)
    --------------------------------------
    nanovolt-divider.kicad_dru conditions all three 450 V rules on NetClass == 'HV',
    but the project file had "netclass_patterns": [] and no HV class, so every one of
    them matched nothing. DRC reported "0 violations" whether the board was safe or
    not. The original patterns matched auto-generated names like Net-(J3-Pin_1) and
    were dropped when KiCad rewrote the project file.
    The class is back with the patterns spelled out - /HV_IN_P and /HV_DIV, never a
    "HV*" wildcard, which would sweep in HV_SENSE (a 3.3 V logic line). Verified by
    moving R34 next to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
    [control.kicad_sch, nanovolt-divider.kicad_pcb, nanovolt-divider.kicad_sch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]
2026-09-07 docs: schematic review checklist for the pre-routing pass
    ERC and DRC are already clean, so the checklist deliberately skips connectivity,
    floating pins and footprint parity and targets what tooling cannot check:
    intent, physical reality, and margins/failure modes.
    Every net and pin reference in it was cross-checked against the netlist exported
    from a713704 - 64 pin claims, no mismatches.
    Sections: relay channel (one sheet, five instances), range topology and divider
    maths, polarity/inject semantics, measurement node and where thermal EMF actually
    matters, the 450 V path, control section, power, physical reality (the ELEGOO
    pinout, the 3PDT lever mapping, custom footprint pad numbering) an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
2026-09-07 K5 pole B breaks the return leg: ISOLATE now opens both sides
    Pole A already broke the high side (RANGE_BUS -> INJ_NODE); pole B was unused
    with all three pins no-connect. It now breaks the return in step with it:
    SRC_RTN -> K5 B_COM, K5 B_NO -> INJ_RTN -> 3PDT pole 2 NORMAL throw.
    In ISOLATE the programmable source is now detached from the 1 ohm and the DMM
    path at both ends, so none of it - output capacitance, cabling, leakage to earth
    - stays attached to the measurement node.
    SRC_RTN and INJ_RTN are carried by net label rather than a polyline: a drawn wire
    from K5 pole B across to the switch would have to cross both INJ_NODE and HV_DIV.
    Net changes: /SRC_RTN is now K4.8 + K5.8 (was K4.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
    [nanovolt-divider.kicad_pcb, nanovolt-divider.kicad_sch]
2026-09-07 Pin the repo to LF endings
    core.autocrlf=true wanted CRLF in the working tree, but the generators and KiCad
    both write LF. Every run of tools/gen_schematics.py therefore left the generated
    files permanently "modified" with an empty diff, which hides real board changes
    and buries the log in LF/CRLF warnings.
    "* text=auto eol=lf" settles it; renormalisation staged no content changes,
    confirming the committed blobs were already LF. Images and other binaries are
    marked explicitly so they are never touched.
    No schematic or board content changed: ERC 0, DRC 0 errors, 0 schematic-parity
    issues, HV netclass intact.
    Claude-Session: https://clau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
2026-09-09 Solder the display harness: J7-J9 become wire pads, board shrinks to 60x94
    The board specified JST_XH_B4B-XH-A (2.50 mm) for J7/J8/J9, but the
    ESP32-2432S028R's P1/CN1/P3 are 1.25 mm-class connectors. That header
    never mated with anything: it meant crimping a bespoke pitch-bridging
    cable for a joint that never needs to unmate. Solder the module's own
    supplied pigtail to the board instead and the header, the crimping and
    the pitch mismatch all go away at once. The module end keeps its
    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
    [control.kicad_sch, nanovolt-divider.kicad_pcb]
2026-09-09 Correct the DRC claim in gen_pcb.py, and document its UUID churn
    The docstring said "runs kicad-cli for the netlist, the format upgrade
    and DRC". It does the first two; it has never run DRC. Say what it
    actually does, point at the command, and warn that the report will not
    be empty while the board is unrouted so nobody reads the baseline as a
    regression.
    Also record something that costs real time to rediscover: re-running the
    script is not idempotent. kicad-cli pcb upgrade assigns fresh random
    UUIDs to the graphics it materialises inside stock footprints, so ~705
    of the board's ~1521 UUIDs change on every run and the file reads as
    heavily modified when nothing about the board did. The 8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
    [gen_pcb.py]
2026-09-09 README: call out the non-deterministic board regeneration properly
    This has now been rediscovered three times, each time as an
    investigation into whether a regeneration silently broke the board. The
    gen_pcb.py docstring mentions it, but nobody reads a docstring before
    running a script - put it in the README under its own heading, next to
    the generator docs where the diff is actually encountered.
    Includes the normalisation snippet (verified: reports True both on a
    clean tree and immediately after a regeneration that git scores as
    705 insertions / 705 deletions), and the reason to decode both sides as
    bytes - decoding one through subprocess text=True uses the locale codec
    and invents differen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
2026-09-10 Swap the TMP117 for a TMP275: SOIC-8, so it can be hand-soldered
    The TMP117 only ships as a DSBGA-6 on a 0.4 mm ball pitch, which is not
    hand-assemblable, and this board is built by hand. TMP275AIDR is SOIC-8
    at 1.27 mm pitch and keeps address 0x48 (A2:A0 all on DGND), so nothing
    else on the I2C bus moves.
    The cost is absolute accuracy: +/-0.5 C and 12-bit (0.0625 C) instead of
    +/-0.1 C and 16-bit (0.0078 C). That is not what this sensor is for - it
    tracks the *change* in the 1 ohm region's temperature for the optional
    ratio correction, and that needs short-term repeatability, not absolute
    accuracy. The register map is not TMP117-compatible, so firmware will
    differ when it is written.
    Sche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
    [control.kicad_sch, nanovolt-divider.kicad_pcb, nanovolt-divider.kicad_sch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]
2026-09-10 Remove the 450 V path: keep the instrument single-purpose
    The HV input shared the 1 ohm low leg, and that shared leg capped what the
    range could ever be. At 10 M the divider drew 45 uA and gave 45 uV out;
    more output meant a smaller high leg, and 1 M draws 450 uA where 10 M
    draws 45 uA. A Geiger supply is built to source microamps into a tube that
    draws almost none, so its output impedance is high - often set by a series
    anode resistor. Against a 1 M source impedance a 10 M divider already
    reads 9% low and a 1 M divider reads 50% low, and that error tracks the
    supply's operating point, so calibration cannot remove it.
    The HV path also had no polarity reversal - K4 serves the NORMAL input
    on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
    [control.kicad_sch, nanovolt-divider.kicad_pcb, nanovolt-divider.kicad_sch]
2026-09-10 Lay the high legs flat and go to M2: board 60 x 83 -> 60 x 72.5
    Two independent constraints were holding the board down, and both were mine
    rather than the design's.
    R31-R33 standing vertically under their relays were 16 mm tall, and R33
    reached y 67.7 with the slots at 68.0 - 0.31 mm of margin. The mounting
    holes, which I had assumed were binding, had 1.55 mm. Flat they are 3.2 mm
    tall and the row clears the relays by 0.55 mm: 9 mm off the board.
    They no longer align one per relay, because they cannot - three 12 mm-plus
    resistors do not fit in three 10.2 mm relay cells. Nothing is lost by that.
    A_NO and B_NO are both on the relay's *upper* contact row, so a resistor
    hanging below the rela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
    [nanovolt-divider.kicad_pcb]
2026-09-10 Fold the harness pads into the MCP23017 row: board 60 x 72.5 -> 60 x 69.1
    The display-module pads had a row of their own above U1, but they are only
    2.9 mm tall against U1's 11.9 - beside it rather than above it they cost no
    height at all. The control band is now one row:
    [H1] P1/CN1 | C1,C3 | U1 | C4,R21 | R22,R23 [H2]
    P1 is stacked above CN1 rather than beside it. Side by side the two groups
    are 17.2 mm wide and the band needs 48.2 mm of the 49.1 mm between the top
    mounting holes, which does not fit - the right-hand columns' designators
    overlapped their neighbours. Stacked the block is 11.1 mm wide and 7.7 mm
    tall, still inside U1's band, so the width comes free. P1 and CN1 are
    separat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
    [nanovolt-divider.kicad_pcb]
2026-09-10 Place the control-band passives by net rather than by what fit
    U1's VDD(9), VSS(10), SCL(12) and SDA(13) are all on its lower pad row at
    x 36.3-41.4 and ~RESET(18) on the upper row, while power and I2C both arrive
    at the harness on the far left. The three passive columns now follow that:
    L1, at the power entry : C3 22u 5 V bulk, C4 22u 3V3 bulk
    L2, adjacent to U1 : R21 SDA and R22 SCL pull-ups
    R1, right of U1 : R23 ~RESET pull-up (upper, level with pin 18)
    C1 100n across VDD/VSS (lower, level with 9/10)
    The pull-ups were on the far side of U1, which made the I2C bus run out past
    pin 13 and back. Between CN1 and U1 it is monotonic. Measured pad to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
    [nanovolt-divider.kicad_pcb]
2026-09-11 Route the board: first pass, DRC 0 errors / 0 unconnected
    The precision path and anything with design intent is laid by hand in
    tools/route_hand.py; a grid maze router (tools/route_pcb.py) fills in the
    rest around it. DRC goes from 140 unconnected to 0, with 0 errors. The 64
    silk_over_copper warnings are the same set the unrouted board had.
    MEAS_NODE / ANALOG_RTN one tight B.Cu pair, K5 to R35, via-free. RTN faces
    the high-leg pads and takes their surface leakage.
    It splits only under R35, along its axis.
    R35 injection current lands on the pads from inside,
    J5/J6 sense leaves them outside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
    [nanovolt-divider.kicad_pcb]
2026-09-11 Tidy silkscreen after routing: 64 -> 56 silk_over_copper warnings
    Hand pass over the routed board. Copper is untouched: same 1410 mm of
    track, same 101 vias, no footprint moved.
    Q1-Q8 reference designators and the J1/J2/J5/J6 value text moved off pads.
    Board labels repositioned (title, NORM IN, OUT HI, OUT LO); NORM HI and
    NORM LO added at the input pads; name / revision / author block added.
    DRC: 0 errors, 0 unconnected. The 56 remaining warnings are all
    silk_over_copper (silkscreen clipped by solder mask), which the fab clips
    anyway; judged benign.
    Claude-Session: https://claude.ai/code/session_0128rWrsZDfCzkxQ1CZFxeXp
    [nanovolt-divider.kicad_pcb]
2026-09-11 Remap the MCP23017 GPIOs to the driver order: fan-out 30 vias -> 0
    The coil lines were on GPA0..GPA7 (+ GPB0/1 for K5): the package row that
    faces the board edge, in an order scrambled against the driver columns,
    while GPB2..GPB7 - the row facing the drivers - sat unused. Every line had
    to get off the wrong side of the chip and cross its neighbours.
    GPB0..GPB7 K4 S, K4 R, K1 S, K1 R, K2 S, K2 R, K3 S, K3 R (columns' order)
    GPA0/GPA1 K5 RESET / K5 SET (leave under the package to the right)
    GPA2..GPA7 spare
    The firmware maps GPIO to coil by table; there is no firmware yet, so the
    remap costs nothing there. Schematic change is in gen_schematics.py; only
    control.kicad_sch changes,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
    [control.kicad_sch, nanovolt-divider.kicad_pcb]
2026-09-11 Rev A: rename from Rev0, add the fab files sent to OSH Park
    This is the revision going to fab, and the silkscreen already says Rev A.
    Rev0 -> Rev A in the board and schematic title blocks, both generators, the
    router, README and docs; the spec moves to docs/nanovolt_divider_rev_a.md.
    The generators reproduce the edited title blocks exactly; ERC 0, DRC
    unchanged (0 errors, 0 unconnected, 0 parity, 56 benign silk_over_copper).
    hardware/fab/ holds the Gerbers and drill files byte for byte as uploaded:
    .gitattributes marks the folder -text so their CRLF survives, .gitignore
    lets them through the global *.gbr/*.drl/*.gbrjob ignore and keeps the
    uploaded zip out. They were plotted from 1bad5f9, b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
    [control.kicad_sch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]
2026-09-26 Wire the harness to the display module in hand; add the enclosure
    The Rev A pads were drawn for an assumed ESP32-2432S028R pinout (P1 =
    TX/RX/VIN/GND, CN1 = GND/IO22/IO27/3V3). The Cheap Yellow Display in hand
    has UART/power (RXD, TXD, GND, 5V), 3V3 (3.3V, IO35, nc, GND) and SPI
    (IO23, IO19, IO18, IO27) connectors, and no IO22.
    The board is fabricated, so only the harness and the firmware pins move:
    I2C is now SDA = IO27, SCL = IO18, and J8 is fed by two pigtails. J7's
    silk numbers are reversed against the module (module pin 3 is GND, pad 3
    is +5V), so the docs say to land wires by signal name.
    The netlist is unchanged. The symbols' pin names and descriptions follow
    the module. The harness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
    [back-panel-v0.3MF, back-panel-v0.SLDPRT, banana-plug-wrench-v0.3MF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]
2026-09-26 Add the Rev A firmware: relay state machine, SCPI over USB, touch UI
    PlatformIO project for the CYD (espressif32 7.1.3 / Arduino 2.0.17,
    LovyanGFX). It enforces the spec 6.3 relay rules on top of a one-coil-at-a-time
    pulse driver. The MCP23017 latches are cleared first at boot, because R23 keeps
    the chip out of reset across an ESP32 reboot. Calibration is kept in NVS, with
    a microSD backup and a CSV run log; IO18 is switched between I2C SCL and SD SCK
    around each card access. There are bring-up diagnostics and a simulated-board
    build (cyd_sim).
    Verified on the bare module: relay sequencing (sim), no-board handling, SD
    round-trip, NVS persistence, display (rotated 180 deg for the enclosure)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
    [bus.cpp]
2026-09-27 Calibration protocol, firmware 0.2.0 support, and the bench handoff
    docs/calibration_protocol.md designs the calibration. Run P characterises
    the PSU against room temperature with the meter on IN. Run R measures the
    ratio with the meter on OUT, using ABBA polarity reversal through K4, and
    brackets it with Vin anchors. An optional Run H cycles the high legs on
    ohms: 1E-6/1E-7 tempcos that Run R cannot resolve under natural cycling
    are carried over from 1E-5 through the leg differences. The document
    includes the uncertainty budget and the write-back sequence.
    Firmware 0.2.0:
    - calibration record v2 (k0, T0, alpha, beta, u_k0, u_alpha, span,
    source), stored as one NVS blob per range, with an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
    [main.cpp, pins.h, scpi.py]
2026-09-27 Add the PCB holder 3MF print export
    The SOLIDWORKS part and 3DXML were committed with the enclosure; this is
    its 3MF for printing, matching the other enclosure parts.
    [pcb-holder-v0.3MF]
2026-09-27 Rename the MCP/TMP status lights to BOARD/TEMP
    MCP was a part number with other connotations. BOARD matches the NO BOARD
    banner and SYST:MODE?'s BOARD= field; TEMP says what the TMP275 light is for.
2026-09-27 Banner shows the state as INJECTING / ISOLATED
    The banner and the output button used the same two words, one as a state and
    one as an action, so a glance could not tell which was which. The banner now
    uses participles and the button keeps the verbs. SCPI and the run log keep
    INJECT / ISOLATE.
2026-09-27 Final Rev A mechanical BOM, enclosure print settings, and the cover part
    [cover-v0.3MF, cover-v0.SLDPRT]
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2026-10-03 Enclosure: base plate and cover v1 (two more screws), STEP for every part
    v1 of the base plate and cover adds two M3 screws. The v0 parts were printed
    and work well; v1 supersedes them here. Every enclosure part now ships a
    neutral .STEP alongside the .SLDPRT source and the print-ready .3MF.
    BOM: M3x8 button-head screws and M3x4x4.2 heat-set inserts go from 12 to 14.
    [back-panel-v0.STEP, banana-plug-wrench-v0.STEP, base-plate-v0.3MF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]
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2026-10-03 Prepare for public release: current-state docs, licences, calibration page
    The documentation now describes Rev A as it is, without the design history:
    - README: the public front page, with a board render, capabilities, status,
    and the circuit, board, routing, design-file, fab and enclosure notes in
    present tense. Fixes the board-diff snippet's broken string literals.
    - docs/nanovolt_divider_rev_a.md: the as-built design. Drops the removed
    high-voltage path, planned-vs-built amendments, purchase status, order
    lists and next steps. BOM decoupling counts now match the board, and R23
    (MCP23017 reset pull-up) is listed.
    - docs/host_interface.md (was bench_handoff.md): the USB link, the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
2026-10-03 Calibration step 1: supply characterisation result
    144 h of the supply at 29 V into NORMAL IN, unloaded, against the TMP275.
    Switch-on settling takes ~30 h (-119 ppm). Settled: 29.0055 V at 25 C,
    gamma = -14 +/- 2 ppm/C with a first-order lag of roughly 20-70 min, no
    consistent drift but multi-day wander (residual ADEV ~1 ppm at minutes,
    4 ppm at 17 h). Data, figures and the analysis script are in
    calibration/2026-09-27_supply/.
    Claude-Session: https://claude.ai/code/session_01YExXFfQiJdXG3K1m5b3d5S
    [minute.csv]
2026-10-04 Calibration status: step 2 pending a repeat
    The first high-leg session ran with the IN- panel jack wired to the
    measurement node after the enclosure panels were swapped, so its
    inverted-polarity readings were meaningless. It will be repeated once the
    wiring is corrected.
    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
2026-10-04 README: tighten claims, move design detail to docs/
    The opening now says programmable attenuator for nanovolt-to-microvolt
    experiments with calibration in progress; "true zero" becomes a
    source-disconnected baseline and "no coil heat" becomes no continuous
    coil power. Circuit, harness, board and routing move to docs/hardware.md;
    design-file workflow, generators and fab files to docs/development.md.
    The README keeps photos, capabilities, status, a build path, known
    limitations and licence (345 -> 116 lines). Cross-references updated.
    [gen_pcb.py, gen_schematics.py, pins.h]
2026-10-04 Calibration step 2: high legs by resistance
    2-wire ohms at NORMAL IN with the supply unplugged, 15 ABBA cycles over 3 h.
    R_total: 100,034 ohm (1E-5), 999,710 ohm (1E-6), 10.0071-10.0081 Mohm
    (1E-7), all within part tolerance. The two high-value ranges show a
    leakage-like step (8 and 102 ppm) and a polarity difference (21 and
    102 ppm) scaling steeply with resistance: ~1e11 ohm of leakage, location
    not yet known. 1E-7 is provisional at the 100 ppm level until the ratio run.
    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
    [dwells.csv]
2026-10-04 Calibration step 2: explain the polarity difference, correct one claim
    A reciprocal resistor network cannot read differently with the meter leads
    swapped; the asymmetry needs a third terminal tied to the meter's LO, i.e.
    leakage from precision nodes to the control ground, which reaches the meter
    chassis through USB, the host and GPIB. A thermal EMF is ruled out by how
    the difference scales across ranges.
    Corrects the earlier statement that averaging the two polarities cancels
    the effect: that holds for an EMF, not for leakage. Adds why ratio-mode
    measurements should be immune to leakage to ground, and the planned
    USB-disconnect check.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
2026-10-05 Calibration step 3 (b): null with the input shorted
    24 h of the full ratio-run schedule with a copper link across NORMAL IN:
    mean block signal -1.1 +/- 1.3, -1.2 +/- 1.2 and +1.9 +/- 1.2 nV on 1E-5,
    1E-6 and 1E-7 (pooled -0.1 +/- 0.7 nV). No switching bias. Blocks scatter
    by 13 nV, half the 26 nV assumed, so the ratio run's statistical limits on
    k0 halve to about 2.5 / 25 / 250 ppm.
    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
    [blocks.csv, dwells.csv]
2026-10-05 Calibration step 2: correct the polarity-difference explanation
    The control-ground leakage hypothesis was tested and ruled out: with the
    divider's USB unplugged (latching relays holding), 1E-7 still reads
    N - I = +79 ppm. Open-circuit DC volts at IN found a ~12 uV series EMF on
    the 1E-7 chain that flips with K4, which accounts for roughly a third of the
    1E-7 difference; the rest, and the 1E-6 difference, remain unexplained.
    Neither affects the ratio. Measurements in followup_2026-10-05.json.
    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
2026-10-09 Calibration step 4: the ratio run
    72 h at 29 V, 270 ABBA blocks per range, V_in from anchors before and after
    (supply model closes them to 4.7 ppm over 81 h). k0 at 25.3 C:
    9.98131e-6 (-1859 ppm, +/-2.4 stat), 9.98234e-7 (-1765, +/-19),
    9.9646e-8 (-3545, +/-297). alpha on 1E-5 +11 +/- 4 ppm/C; unresolved on
    1E-6 and 1E-7. Null (a) -0.3 +/- 0.8 nV; block-paired range ratios agree
    with the k0 values. The R_L consistency check is open: k0 x R_total spreads
    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
    [blocks_k.csv, blocks_s.csv]
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2026-10-17 Firmware 0.2.2: the TMP275 line is a span check, not a tempco readout
    The second readout line showed Tref and alpha, which for records without a
    temperature correction is noise. It now shows the temperature and the
    record's validated span, both amber when outside it ("outside 21.0-27.3 C"),
    or "cal UNSAVED" while the working copy differs from NVS. alpha appears only
    when a record carries a non-zero tempco. u beside k is always dim.
    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
2026-10-17 Temperature monitored, not corrected: records v2 and the reasoning
    The records now carry alpha = beta = 0, with the possible tempco folded into
    u_k0 over the 21.0-27.3 C span (37 / 77 / 344 ppm). New section explains why:
    unresolved on 1E-6/1E-7; on 1E-5 not separable from the meter's own tempcos;
    a live correction would use the unlagged temperature; 3.2 nV/C at most. The
    first write-back is kept as superseded. README, design doc and the
    instrument's SD export and history updated; firmware 0.2.2.
    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
